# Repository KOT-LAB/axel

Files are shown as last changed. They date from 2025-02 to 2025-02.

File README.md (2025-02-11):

# Axel: Your framework for custom BLDC motor controller

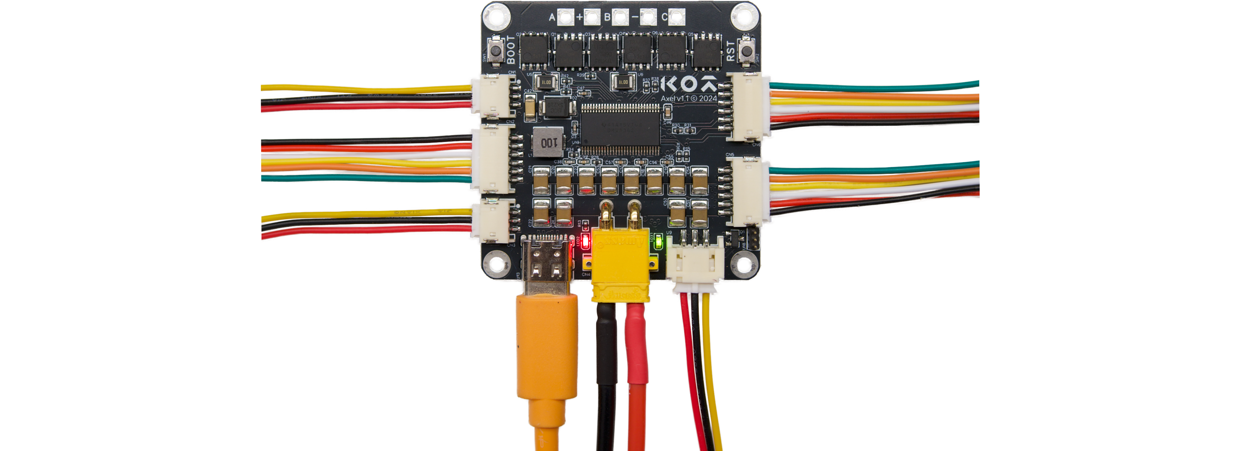
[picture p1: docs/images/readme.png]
Axel Board
  

---

## 🚀 What is Axel?

Axel is an **open-source BLDC motor controller** designed to empower makers, enthusiasts, and researchers. It's a versatile hardware framework for developing custom firmware tailored to your specific application. Think of it as your "**Arduino for BLDC motor control**," combining flexibility, user-friendliness, and powerful performance to support a wide range of projects for both beginners and professionals.

### **Key Advantages:**
- **Flexibility In Motor-Controller Setup:** Features a built-in encoder for direct mounting on the motor and also supports external encoders.
- **Built-in Current Sensing:** Enables true Field-Oriented Control (FOC) for precise and efficient motor control.
- **High-Performance:** Based on the STM32 and a powerful gate driver with external MOSFETs, meets demands of any application.
- **Extensive Connectivity:** Has all most popular interfaces on board, makes the integration with your application seamless.
- **Full compatibility with SimpleFOC:** Makes it easy to start for beginners and enables rapid development for professionals.
- **Flexible Development:** Write your own firmware from scratch to maximize performance, or customize our basic firmware and leverage full SimpleFOC compatibility for rapidness.
- **Beginner-Friendliness:** SimpleFOC support, clear documentation, basic firmware that works out of the box, and an extensive set of examples make getting started easy.

### Applications

- **Legged Robots:** High-speed and high-precision motion control for dynamic robotics.
- **Exoskeletons:** Reliable torque and speed control for assistive devices.
- **Electric Vehicles:** Scalable design for mobility solutions.
- **CNC Machines & 3D Printers:** Precise control in automated manufacturing.
- **Anything else:** The only limit is your imagination!

### **Is Axel for you?**

- **Enthusiasts**: Power *any project* with a *versatile* and *high-performance* BLDC motor controller that’s easy to integrate and customize.
- **Researchers**: Explore cutting-edge motor control concepts with a platform designed for *experimentation and innovation*. Axel provides a *powerful framework* for developing, testing, and iterating on new ideas.
- **Startups**: Jump straight into developing a *tailor-made solution* for your application. No need to set up manufacturing. Its *rich base of examples* and *SimpleFOC support* make firmware development easy and efficient.
- **Enterprises**: Minimize *external dependencies* by building your *custom in-house solution* on Axel. Perfect for *fast internal development* and *prototyping* before committing to large-scale designs.

---

## 📈 Project Status

**In January 2025, we decided to turn Axel from a solely hardware project into a software one as well.** Now, we've started actively working on `/tests`, `/examples`, and `/firmware`. Expect first commits in February!

### **Current Development Stage:**

- **Production Status:** Axel’s production is **currently frozen** due to a recently discovered major hardware bug. We are diligently working to resolve this issue.
- **Example Code Development:** Expanding the `/examples` directory with practical applications and demonstrations.
- **Firmware Development:** Actively working on a basic firmware that serves as a solid foundation for your custom firmware development in `/firmware`.
- **Hardware Tests:** Focused on enriching hardware validation tests to ensure reliable performance in `/tests`.

---

## 📊 Main Parameters

| **Parameter** | **Value** |
|---|---|
| **Input Voltage** | 10-54V |
| **Peak Phase Current** | 100A |
| **Peak Electrical Power** | 3100W |
| **Continuous Electrical Power** | 1100W |
| **MCU** | STM F446RE |
| **Driver** | TI DRV8302 |
| **Encoder** | AS5047P |
| **Interfaces** | SPI, I2C, CAN FD, UART, USB-C |
| **Programming interfaces** | SWD, DFU |
| **Dimensions** | 50x50x9mm |

---

## 🛠️ Dive deeper & How it works

For more in-depth information about Axel, refer to the following documents:

- **[Hardware Details](docs/hardware.md)** – Explore hardware features, the PCB design, schematics, and component choices behind Axel.
- **[SimpleFOC Support](docs/simplefoc_support.md)** – Understand how Axel integrates with SimpleFOC for simplified motor control development.
- **[Getting Started](docs/getting_started.md)** – Begin using Axel with setup instructions, toolchain details, and firmware installation.
- **[Documentation](docs/README.md)** - Learn more about Axel.

These documents provide essential details for both beginners and advanced users who want to make the most of Axel.

---

## 🗂️ Directory Structure

```
Axel/
├── hardware/               # Schematics, PCB layouts, photos, hardware docs, 3D models
│   ├── schematics/         # Circuit diagrams and electrical schematics
│   ├── mechanical/         # 3D models, enclosures, and mounting designs
│   └── media/              # Renders and photos of Axel
├── firmware/               # (coming soon) Base firmware for custom development
├── examples/               # (coming soon) Example code for different control modes
├── tests/                  # (coming soon) Hardware tests
├── utils/                  # Utils for development
├── docs/                   # Additional documentation & images
├── LICENSE                 # MIT License for firmware
├── LICENSE-HARDWARE.md     # CERN-OHL-P License for hardware
└── README.md               # This file
```

---

## 🙏 Credits and Special Thanks

This project wasn't possible without the active members of Axel's team. Special thanks to:

- ***Arsenii Mironov*** - idea, project management, software and setting up manufacturing
- ***Peter Germanovich*** - product management
- ***Andrei Belov*** - electrical engineering
- ***Alina Petrovskaya*** - marketing materials
- ***Richard Unger*** - advising on hardware design
- ***Rostislav Likhogrud*** - general supervision

Axel’s development was inspired by the incredible work of the open-source community. Special thanks to:

- **[MIT Mini Cheetah Controller](https://github.com/bgkatz)** by ***Ben Katz*** – A key reference during Axel’s hardware design.

---

## 🤝 Contribution and Support

We welcome contributions to Axel! Whether it’s code, hardware feedback, or documentation improvements, please check out our **[CONTRIBUTING.md](CONTRIBUTING.md)** to get started.

If you’ve found an issue or have a feature request, feel free to **[open an issue](https://github.com/KOT-LAB/axel/issues)**.

Another great way to support the team and future development is to buy our hardware at **[Emotor.Market](https://emotor.market/)**. Axel will be available again there at the best price once the final bugs are resolved.

---

## 📜 License

Axel is licensed under a dual-license model:

- **Firmware:** Licensed under the **[MIT License](LICENSE)**. This allows for free use, modification, and distribution of the firmware, even for commercial purposes, with proper attribution.
- **Hardware:** Licensed under the **[CERN Open Hardware License (CERN-OHL-P)](LICENSE-HARDWARE.md)**. This ensures that any modifications or derivatives of the hardware design remain open-source.

---

## 📬 Contact

For questions, feedback, or commercial inquiries, reach us at **[made@kot.works](mailto:made@kot.works)**.

---

*Built with passion for makers, innovators, and dreamers. Let Axel power your next big idea!*

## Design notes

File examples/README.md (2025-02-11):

# Axel Examples  

This directory contains example projects demonstrating various control modes and functionalities of the Axel controller. Each example is organized as a standalone **[PlatformIO](https://platformio.org/)** project on the **[Arduino framework](https://docs.platformio.org/en/latest/frameworks/arduino.html)**, making it easy to compile and upload to the board.  

---

## Structure  

Each example follows the standard **[PlatformIO](https://platformio.org/)** project structure:  

```
example/
├── src/                   # Source code files
├── include/               # Header files
├── lib/                   # External libraries (e.g., SimpleFOC)
├── platformio.ini         # Project configuration file
└── README.md              # Description of the example
```

---

## Available Examples  

- `blink`  
- `basic_position_control`  
- `basic_velocity_control`  
- `basic_torque_control`  
- `advanced_position_control`  

Each example has its own `README.md` with details on functionality, usage, and expected behavior.  

---

## Getting Started  

1. Open an example directory in PlatformIO.  
2. Refer to the example-specific README for configuration and usage details.  
3. Build and upload the project to your Axel board.  

---

For more information on using PlatformIO with Axel, refer to the main [firmware/](../firmware/) README.

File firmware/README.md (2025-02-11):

# Axel Basic Firmware

Welcome to the **Axel Firmware** directory! This firmware serves as a **foundation** for developing custom BLDC motor control applications using the Axel controller.

---
## ⚠️ Announcement

**In January 2025, we decided to turn Axel from a solely hardware project into a software one as well.** Now, we've started actively working on `/tests`, `/examples`, and `/firmware`. Expect first commits in February!

Currently, we are resolving a **major hardware bug** that was recently discovered. Once this issue is resolved, we will implement the basic firmware according to its description in this file. Development is actively ongoing!

---

## 🚀 Overview

This **basic firmware** is organized as a **[PlatformIO](https://platformio.org/)** project, making it easy to build, upload, and manage dependencies across different development environments. 

For simplicity and ease of development, this firmware is based on **[SimpleFOC](https://github.com/simplefoc/Arduino-FOC)**, a widely-used open-source library for BLDC motor control. Learn more about Axel's compatibility with SimpleFOC [docs/simplefoc_support.md](../docs/simplefoc_support.md).

This **"basic" firmware** aims to:

- Provide **basic motor control functionality** out of the box.
- Ensure the **board operates correctly** with minimal configuration.
- Serve as a **starting point** for custom firmware development.

---

## ⚙️ Features

- **Motor Control:** implements control in position, velocity, and torque modes.
- **Sensor Integration:** uses on-board encoder.
- **Communication Interfaces:** uses CAN FD as a main control bus and can be configured via USB-C for your specific setup.
- **SimpleFOC Integration:** Easy-to-understand APIs for rapid development.

---

## 📂 Directory Structure

```
firmware/
├── src/                   # Source code files
├── include/               # Header files
├── lib/                   # External libraries (SimpleFOC, etc.)
├── platformio.ini         # Project configuration file (PlatformIO)
└── README.md              # This file
```

---

## ⚡ Getting Started

1. **Review our basic getting started guide at [docs/getting_started.md](../docs/getting_started.md)**.

2. **Clone the Repository:**
   ```bash
   git clone https://github.com/KOT-LAB/axel.git
   cd axel/firmware
   ```
3. **Build and Upload:**
   ```bash
   pio run --target upload
   ```

---

## 📚 Documentation

- **Axel Hardware Documentation:** Refer to the `/docs` directory in the main repository.
- **SimpleFOC Documentation:** [https://docs.simplefoc.com/](https://docs.simplefoc.com/)

---

## 🤝 Contributions

We welcome contributions to improve the firmware. Check out the main [CONTRIBUTING.md](../CONTRIBUTING.md) for guidelines.

---

*Happy hacking and motor controlling with Axel!*

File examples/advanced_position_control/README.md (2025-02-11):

# Advanced Position Control example

## Overview

This example demonstrates **position control** on the Axel controller using the SimpleFOC library **with inline current sensing**. It is based on the [official SimpleFOC examples](https://github.com/simplefoc/Arduino-FOC/blob/master/examples/motion_control/position_motion_control/magnetic_sensor/angle_control/angle_control.ino) and closely follows the recommended practices for inline current sensing outlined in the [SimpleFOC documentation](https://docs.simplefoc.com/inline_current_sense). The firmware configures the motor for **position-based control**, sets up the on-board encoder and driver, and **activates current sensing** to improve performance, reliability, and protection.

> **Note:** Unlike the [basic_position_control](../basic_position_control) example, this **advanced example** takes advantage of Axel’s **current sensing capability** for better FOC performance and real-time current monitoring.

---

## Objectives

- Show **SimpleFOC's seamless integration** with Axel.
- Set up the Axel's specific hardware: **on-board AS5047P encoder**, **DRV8302 driver** and **current sensing**.
- Demonstrate how to **integrate and utilize current sensing** in Axel’s FOC workflow.
- Show **improved current feedback**, resulting in **more efficient torque controle*.
- Illustrate the recommended initialization order and usage of `current_sense` in code in conjunction with the **on-board DRV8302 driver** and **AS5047P encoder**.

---

## Why Use Current Sensing?

The inclusion of current sensing significantly boosts the controller’s capabilities:

1. **Improved FOC accuracy**: By monitoring phase currents in real time, the controller can maintain **more precise field alignment** and deliver superior torque performance.
2. **Overcurrent protection**: Real-time current feedback helps you **detect and prevent dangerous overcurrent conditions** quickly, safeguarding your hardware.
3. **Enhanced tuning**: Being able to observe and fine-tune current loops offers **deeper insight** into motor behavior, allowing for tighter control and **improved efficiency**.

---

## Setup Instructions

This example uses the same fundamental setup as the **basic_position_control** example, but adds pins and configuration parameters for current sensing.

### 1. General Hardware Setup

Before using this example, ensure you have assembled your **motor and controller** correctly. Please refer to **[`hardware_setup.md`](./docs/hardware_setup.md)** for a step-by-step guide.

### 2. Connecting the Axel Controller

To run this example, follow these steps:

1. **Power the Board:**
   - Ensure that the Axel controller is connected to a **suitable power source**.
   - The **main power supply** should match the `#define SUPPLY_VOLTAGE` set in `main.cpp`.
2. **Connect USB-C:**
   - Connect **USB-C** to your computer to enable **serial logging, debugging and control interface**.
3. **Choose an Upload Method:**
   - You can upload the firmware using either **SWD (ST-Link)** or **DFU (Device Firmware Upgrade)**.
   - Edit `platformio.ini` to select the appropriate upload method:

   #### **Using ST-Link (default method)**

   ```ini
   upload_protocol = stlink
   ```

   #### **Using DFU (alternative method)**

   ```ini
   ; upload_protocol = stlink  ; Comment this out
   upload_protocol = dfu       ; Uncomment this to use DFU mode
   ```

### 3. Configure #define Values in main.cpp

Edit the following parameters to fit your **specific hardware** and tuning needs:

- **Motor pole pairs:** `#define MOTOR_POLE_PAIRS`
- **Power supply voltage:** `#define SUPPLY_VOLTAGE`
- **Control parameters (e.g., PID gains, velocity limits, etc.)`

---

## Building and Running the Example

### 1. Build the Project

Open a terminal in the project directory and run:

```bash
pio run
```

### 2. Upload the Firmware

```bash
pio run --target upload
```

### 3. Monitor the Serial Output

Once uploaded, monitor the serial output:

```bash
pio device monitor -b 115200
```

---

## Expected Behavior

When you run this example, you should observe:

- **Initialize the serial monitor and debugging.**
- **Set up and calibrate the magnetic sensor.**
- **Configure the driver (including any DRV8302-specific settings).**
- **Motor and current sense initialization**
- **Initialize the BLDC motor with the appropriate FOC settings and PID parameters.**
- **Real-time current feedback used within the FOC loop for precise torque control**.
- **Continuously run the FOC algorithm and adjust the motor’s position based on the serial input target.**

---

If anything doesn’t work as expected, check your wiring, power supply, and motor parameters. For further assistance, feel free to reach out! 🚀

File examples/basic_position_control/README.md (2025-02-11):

# Basic Position Control example

## Overview

This example demonstrates **position control** on the Axel controller using the SimpleFOC library. It is based on the [official SimpleFOC example](https://github.com/simplefoc/Arduino-FOC/blob/master/examples/motion_control/position_motion_control/magnetic_sensor/angle_control/angle_control.ino) but has been adapted to work with Axel. The example configures the motor for **position-based control**, setups on-board encoder and driver, and allows position commands via USB-C serial communication.

> **Note:** This is the most basic position control example. It does **not** take advantage of Axel's advanced features like current sensing for FOC. If you need to see how current sensing can be integrated into position control, please refer to the **`[advanced_positin_control](./examples/advanced_position_control)`** directory.

---

## Objectives

- Show **SimpleFOC's seamless integration** with Axel.
- Set up the Axel's specific hardware: **on-board AS5047P encoder** and **DRV8302 driver**.
- Implement **basic positin control** as a foundation for custom firmware enhancements.

---

## Setup Instructions

---

### 1. General Hardware Setup

Before using this example, ensure you have assembled your **motor and controller** correctly. Please refer to **[`hardware_setup.md`](./docs/hardware_setup.md)** for a step-by-step guide.

### 2. Connecting the Axel Controller

To run this example, follow these steps:

1. **Power the Board:**
   - Ensure that the Axel controller is connected to a **suitable power source**.
   - The **main power supply** should match the `#define SUPPLY_VOLTAGE` set in `main.cpp`.
2. **Connect USB-C:**
   - Connect **USB-C** to your computer to enable **serial logging, debugging and control interface**.
3. **Choose an Upload Method:**
   - You can upload the firmware using either **SWD (ST-Link)** or **DFU (Device Firmware Upgrade)**.
   - Edit `platformio.ini` to select the appropriate upload method:

#### **Using ST-Link (default method)**

    ```ini
    upload_protocol = stlink
    ```

#### **Using DFU (alternative method)**

    ```ini
    ; upload_protocol = stlink  ; Comment this out
    upload_protocol = dfu       ; Uncomment this to use DFU mode
    ```

### 3. Configure `#define` Values in `main.cpp`

Before building, make sure to configure the following **user-specific parameters** in `main.cpp` in accordance to your particular setup:

- **Motor pole pairs:** `#define MOTOR_POLE_PAIRS`
- **Power supply voltage:** `#define SUPPLY_VOLTAGE`
- **Control parameters (e.g., PID gains, velocity limits, etc.)`

---

## Building and Running the Example

### 1. Build the Project

From the terminal in the project directory, run:

```sh
pio run
```

### 2. Upload the Firmware

```sh
pio run --target upload
```

### 3. Monitor Serial Output

Once uploaded, monitor the serial output:

```sh
pio device monitor -b 115200
```

---

## Expected Behavior

When you run this example, you can expect it to:

- **Initialize the serial monitor and debugging.**
- **Set up and calibrate the magnetic sensor.**
- **Configure the driver (including any DRV8302-specific settings).**
- **Initialize the BLDC motor with the appropriate FOC settings and PID parameters.**
- **Continuously run the FOC algorithm and adjust the motor’s position based on the serial input target.**

---

If anything doesn’t work as expected, check your wiring, power supply, and motor parameters. For further assistance, feel free to reach out! 🚀

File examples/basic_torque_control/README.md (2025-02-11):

# Basic Torque Control example

## Overview

This example demonstrates **torque control** on the Axel controller using the SimpleFOC library. It is based on the [official SimpleFOC example](https://github.com/simplefoc/Arduino-FOC/blob/master/examples/motion_control/torque_control/magnetic_sensor/voltage_control/voltage_control.ino) but has been adapted to work with Axel. In this example, motor torque is controlled by **setting the voltage** rather than directly reading or regulating current. 

> **Note:** This is the most basic torque control example. It does **not** take advantage of Axel’s advanced features like hardware current sensing. For more advanced control approaches (including true current-based torque control), please refer to other examples or future advanced example directories.

---

## Objectives

- Show **SimpleFOC's seamless integration** with Axel in torque control mode.
- Configure Axel’s specific hardware: **on-board AS5047P encoder** and **DRV8302 driver**.
- Implement **basic voltage-based torque control** as a foundation for more sophisticated FOC solutions.

---

## Setup Instructions

---

### 1. General Hardware Setup

Before using this example, ensure you have assembled your **motor and controller** correctly. Please refer to **[hardware_setup.md](./docs/hardware_setup.md)** for a step-by-step guide.

### 2. Connecting the Axel Controller

To run this example, follow these steps:

1. **Power the Board:**
   - Ensure that the Axel controller is connected to a **suitable power source**.
   - The **main power supply** should match the `#define SUPPLY_VOLTAGE` set in `main.cpp`.
2. **Connect USB-C:**
   - Connect **USB-C** to your computer to enable **serial logging, debugging, and control interface**.
3. **Choose an Upload Method:**
   - You can upload the firmware using either **SWD (ST-Link)** or **DFU (Device Firmware Upgrade)**.
   - Edit `platformio.ini` to select the appropriate upload method:

#### **Using ST-Link (default method)**

```ini
upload_protocol = stlink
```

#### **Using DFU (alternative method)**

```ini
; upload_protocol = stlink  ; Comment this out
upload_protocol = dfu       ; Uncomment this to use DFU mode
```

### 3. Configure `#define` Values in `main.cpp`

Before building, make sure to configure the following **user-specific parameters** in `main.cpp` in accordance with your particular setup:

- **Motor pole pairs:** `#define MOTOR_POLE_PAIRS`
- **Power supply voltage:** `#define SUPPLY_VOLTAGE`
- **Control parameters (e.g., alignment voltage, etc.)**

---

## Building and Running the Example

### 1. Build the Project

From the terminal in the project directory, run:

```sh
pio run
```

### 2. Upload the Firmware

```sh
pio run --target upload
```

### 3. Monitor Serial Output

Once uploaded, monitor the serial output:

```sh
pio device monitor -b 115200
```

---

## Expected Behavior

When you run this example, you can expect it to:

- **Initialize the serial monitor and debugging.**
- **Set up and calibrate the magnetic sensor.**
- **Configure the driver (including any DRV8302-specific settings).**
- **Initialize the BLDC motor with the appropriate FOC settings and PID parameters.**
- **Continuously run the FOC algorithm and adjust the motor’s torque (voltage) based on the serial input target.**

---

If anything doesn’t work as expected, check your wiring, power supply, and motor parameters. For further assistance, feel free to reach out! 🚀

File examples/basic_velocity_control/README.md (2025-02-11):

# Basic Velocity Control example

## Overview

This example demonstrates **velocity control** on the Axel controller using the SimpleFOC library. It is based on the [official SimpleFOC example](https://github.com/simplefoc/Arduino-FOC/blob/master/examples/motion_control/velocity_motion_control/magnetic_sensor/velocity_control/velocity_control.ino) but has been adapted to work with Axel. The example configures the motor for **velocity-based control**, sets up the on-board encoder and driver, and allows velocity commands via USB-C serial communication.

> **Note:** This is the most basic velocity control example. It does **not** take advantage of Axel's advanced features like current sensing for FOC. If you need to see how current sensing can be integrated into your motor control, please refer to the **`[advanced_velocity_control](./examples/advanced_velocity_control)`** directory or other advanced examples.

---

## Objectives

- Demonstrate **SimpleFOC's seamless integration** with Axel for velocity control.
- Configure Axel’s specific hardware: **on-board AS5047P encoder** and **DRV8302 driver**.
- Implement **basic velocity control** as a foundation for custom firmware enhancements.

---

## Setup Instructions

---

### 1. General Hardware Setup

Before using this example, ensure you have assembled your **motor and controller** correctly. Please refer to **[`hardware_setup.md`](./docs/hardware_setup.md)** for a step-by-step guide.

### 2. Connecting the Axel Controller

To run this example, follow these steps:

1. **Power the Board:**
   - Ensure that the Axel controller is connected to a **suitable power source**.
   - The **main power supply** should match the `#define SUPPLY_VOLTAGE` set in `main.cpp`.
2. **Connect USB-C:**
   - Connect **USB-C** to your computer to enable **serial logging, debugging, and control interface**.
3. **Choose an Upload Method:**
   - You can upload the firmware using either **SWD (ST-Link)** or **DFU (Device Firmware Upgrade)**.
   - Edit `platformio.ini` to select the appropriate upload method:

#### **Using ST-Link (default method)**

```ini
upload_protocol = stlink
```

#### **Using DFU (alternative method)**

```ini
; upload_protocol = stlink  ; Comment this out
upload_protocol = dfu       ; Uncomment this to use DFU mode
```

### 3. Configure `#define` Values in `main.cpp`

Before building, make sure to configure the following **user-specific parameters** in `main.cpp` according to your setup:

- **Motor pole pairs:** `#define MOTOR_POLE_PAIRS`
- **Power supply voltage:** `#define SUPPLY_VOLTAGE`
- **Control parameters (PID gains, velocity ramp, etc.)**

---

## Building and Running the Example

### 1. Build the Project

From the terminal in the project directory, run:

```sh
pio run
```

### 2. Upload the Firmware

```sh
pio run --target upload
```

### 3. Monitor Serial Output

Once uploaded, monitor the serial output:

```sh
pio device monitor -b 115200
```

---

## Expected Behavior

When you run this example, you can expect it to:

- **Initialize the serial monitor and debugging.**
- **Set up and calibrate the magnetic sensor.**
- **Configure the driver (including any DRV8302-specific settings).**
- **Initialize the BLDC motor with the appropriate FOC settings and PID parameters.**
- **Continuously run the FOC algorithm and adjust the motor’s velocity based on the serial input target.**

---

If anything doesn’t work as expected, check your wiring, power supply, and motor parameters. For further assistance, feel free to reach out! 🚀
```

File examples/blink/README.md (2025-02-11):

# Blink Example for Axel

## Overview

This example demonstrates a simple **LED blink** program on the Axel controller using the **Arduino framework**. It verifies that the board is correctly powered and running firmware by toggling the onboard LED.

---

## Objectives

- Verify that the **Axel board** is powered and functioning correctly.
- Demonstrate **basic GPIO control** using the onboard LED.
- Provide a minimal **PlatformIO project setup** for Axel.

---

## Setup Instructions

### 1. General Hardware Setup

Before using this example, ensure your **Axel board is connected properly**. Please refer to **`./docs/hardware_setup.md`** for general setup instructions.

---

### 2. Connecting the Axel Controller

To run this example, follow these steps:

1. **Power the Board:**
   - Ensure that the Axel controller is connected to a **suitable power source**.
2. **Connect USB-C:**
   - Connect **USB-C** to your computer to enable **serial logging and debugging** (if needed).
3. **Choose an Upload Method:**
   - You can upload the firmware using either **SWD (ST-Link)** or **DFU (Device Firmware Upgrade)**.
   - Edit `platformio.ini` to select the appropriate upload method:

#### **Using ST-Link (default method)**
```ini
upload_protocol = stlink
```

#### **Using DFU (alternative method)**
```ini
; upload_protocol = stlink  ; Comment this out
upload_protocol = dfu       ; Uncomment this to use DFU mode
```

---

### 3. Configure `#define` Values in `main.cpp`

Before building, you can modify the **blink interval** by adjusting the delay values inside `main.cpp`:

```cpp
#define BLINK_DELAY 500 // Change to modify blink rate
```

---

## Building and Running the Example

### 1. Build the Project

In the terminal, navigate to the project directory and run:

```sh
pio run
```

### 2. Upload the Firmware

```sh
pio run --target upload
```

### 3. Monitor Serial Output (Optional)

Although this example does not include serial logging, you can open a serial monitor to confirm board activity:

```sh
pio device monitor -b 115200
```

---

## Expected Output

- The **onboard LED** (connected to `PA2`) should continuously **blink** at a 1-second interval (500ms ON, 500ms OFF).
- If the LED is not blinking, check:
  - Power supply.
  - Upload method (SWD or DFU).
  - Correct PlatformIO configuration.

---

This example provides a simple way to test GPIO functionality on Axel. If the LED is blinking, your board is working correctly! 🚀

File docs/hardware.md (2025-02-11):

# Axel Hardware Overview

Axel is designed as a versatile, high-performance open-source BLDC motor controller. This document details the core hardware components and interfaces that make Axel a powerful and flexible solution for motor control applications.

---

## ⚙️ Key Components

Axel integrates carefully selected components to achieve high efficiency, precision, and versatility:

- **Microcontroller:** STM32F446RE  
  - 180MHz Cortex-M4F MCU with DSP and floating-point unit.
  - Rich set of peripherals suitable for motor control applications.
  - High computational performance optimal for even most demanding applications.

- **Motor Driver:** TI DRV8302  
  - Three-phase gate driver for BLDC motors for high-power applications
  - Supports a wide operating voltage range of **8V to 60V**.
  - Integrated overcurrent protection.

- **Encoder:** AS5047P  
  - High-resolution **14-bit rotary position sensor**.
  - Capable of high-speed angular measurement over **360 degrees**.
  - Dynamic angle error compensation for precise feedback in high-speed motor control.

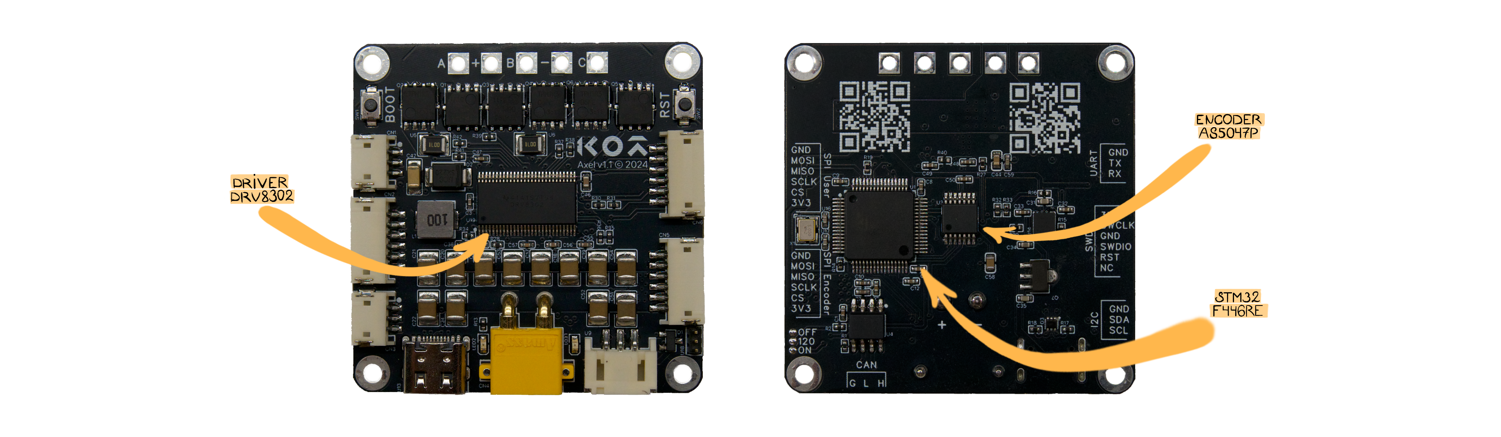
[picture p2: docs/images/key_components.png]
Key Components


---

## 🔌 Interfaces

Axel is equipped with multiple communication and control interfaces to ensure maximum compatibility with various applications:

### **Communication Interfaces**
- **x2 SPI (Serial Peripheral Interface)**  
  - High-speed communication with external encoders and sensors.
  - Can be used as a control bus in specific applications.

- **x1 I2C (Inter-Integrated Circuit)**  
  - Suitable for low-speed sensor interfacing (e.g., thermistors, IMUs, environmental monitors).

- **x1 CAN FD (Controller Area Network - Flexible Data Rate)**  
  - Robust, high-speed communication standard for distributed control systems.
  - Ideal for applications in robotics, automotive, and industrial automation.

- **x1 UART (Universal Asynchronous Receiver-Transmitter)**  
  - Commonly used for debugging, calibration, and interfacing with external modules.

- **x1 USB Type-C**  
  - High-speed data exchange.
  - Supports debugging, DFU (Device Firmware Upgrade) flashing, and serial communication.

### **Programming Interfaces**
- **SWD (Serial Wire Debug)**  
  - Standard ARM debugging interface.
  - Used for firmware development and real-time debugging.

- **DFU (Device Firmware Upgrade)**  
  - Enables firmware flashing over USB without external programmers.

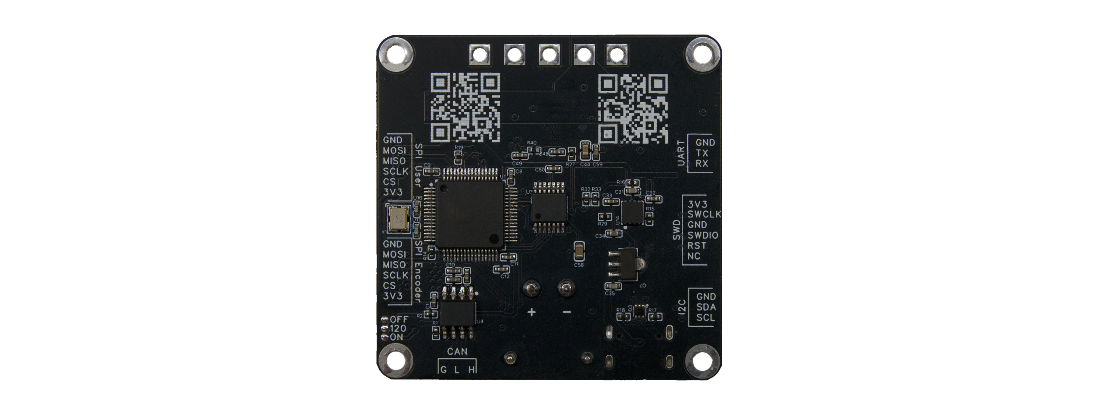
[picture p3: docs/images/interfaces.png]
Interfaces


---

## 🏗️ Future Enhancements
We continuously improve Axel’s hardware and software ecosystem. If you have suggestions or need additional technical details, feel free to contribute or reach out to the team.

For more information on contributing and getting involved, please refer to **[CONTRIBUTING.md](../CONTRIBUTING.md)**.

---

**Axel – Your open-source platform for powerful and flexible BLDC motor control!**

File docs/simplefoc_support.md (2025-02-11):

# SimpleFOC Support for Axel

## 🔗 **Compatibility with SimpleFOC**

Axel is fully compatible with **[SimpleFOC](https://github.com/simplefoc/Arduino-FOC)**, a popular open-source library for BLDC motor control. This compatibility allows you to:

- **Simplify Development:** Leverage SimpleFOC’s high-level APIs to control motors without deep expertise in BLDC control algorithms.
- **Quick Start:** Run example projects with minimal setup using pre-configured SimpleFOC code.
- **Flexible Customization:** Modify and extend firmware easily, thanks to SimpleFOC’s modular design.

This integration makes Axel the perfect choice for both beginners and advanced developers working on BLDC projects.

---

## ⚙️ Why it works?

All the main components of Axel are fully supported by SimpleFOC:

- **Motor Driver: TI DRV8302**

  - Supported by SimpleFOC for three-phase motor control.
  - More here: **[DRV8302 SimpleFOC Example](https://docs.simplefoc.com/drv8302_example)**.

- **Encoder: AS5047P**

  - A high-resolution magnetic encoder with full compatibility.
  - More here: **[SimpleFOC AS5047 Driver](https://github.com/simplefoc/Arduino-FOC-drivers/tree/master/src/encoders/as5047)**.

- **Microcontroller: STM32F446RE**

  - Supported by SimpleFOC using the STM32 Arduino framework.
  - More here: **[SimpleFOC MCU Support](https://docs.simplefoc.com/stm32\_mcu)**

---

## 🚀 **Getting Started with SimpleFOC**

#### To begin using SimpleFOC with Axel, follow these steps:

##### 1. Installation in Arduino IDE

1. Open **Arduino IDE** and navigate to **Sketch > Include Library > Manage Libraries**.
2. Search for **SimpleFOC** in the Library Manager.
3. Click **Install** on the latest version.

For more details, refer to the **[SimpleFOC Library Download Guide](https://docs.simplefoc.com/library_download)**.

##### 2. Installation in PlatformIO**

1. Open **PlatformIO** in VS Code.
2. In **platformio.ini**, add the following line:
   ```ini
   lib_deps = SimpleFOC
   ```
3. Save the file and run a build to install the library.

For more details, refer to the **[SimpleFOC PlatformIO Guide](https://docs.simplefoc.com/library_platformio)**.

---

## 📖 **Understanding SimpleFOC**

We also encourage you to study **[SimpleFOC's documentation](https://docs.simplefoc.com/)**, particularly the **[Theory Corner](https://docs.simplefoc.com/theory_corner)**, to gain deeper insights into motor control principles.

---

## 🛠 **Working with Axel**

Now that SimpleFOC is installed, explore the `examples/` directory to see practical implementations of BLDC motor control with Axel.

---

## 🔗 **Additional Resources**

- **[SimpleFOC Documentation](https://docs.simplefoc.com/)**
- **[SimpleFOC GitHub Repository](https://github.com/simplefoc/Arduino-FOC)**

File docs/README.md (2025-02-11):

# Documentation

This directory contains essential documentation for understanding and working with Axel. Below is an overview of the available files:

- **getting_started.md** – A guide to setting up and using Axel for the first time.
- **hardware.md** – Detailed information on Axel’s hardware design, including specifications and key components.
- **hardware_setup.md** – Instructions for assembling, connecting, and configuring the hardware.
- **simplefoc_support.md** – Information on Axel’s compatibility with SimpleFOC and integration guidelines.
- **images/** – A collection of images, diagrams, and rendors used in the documentation.

For more details, refer to the individual files.

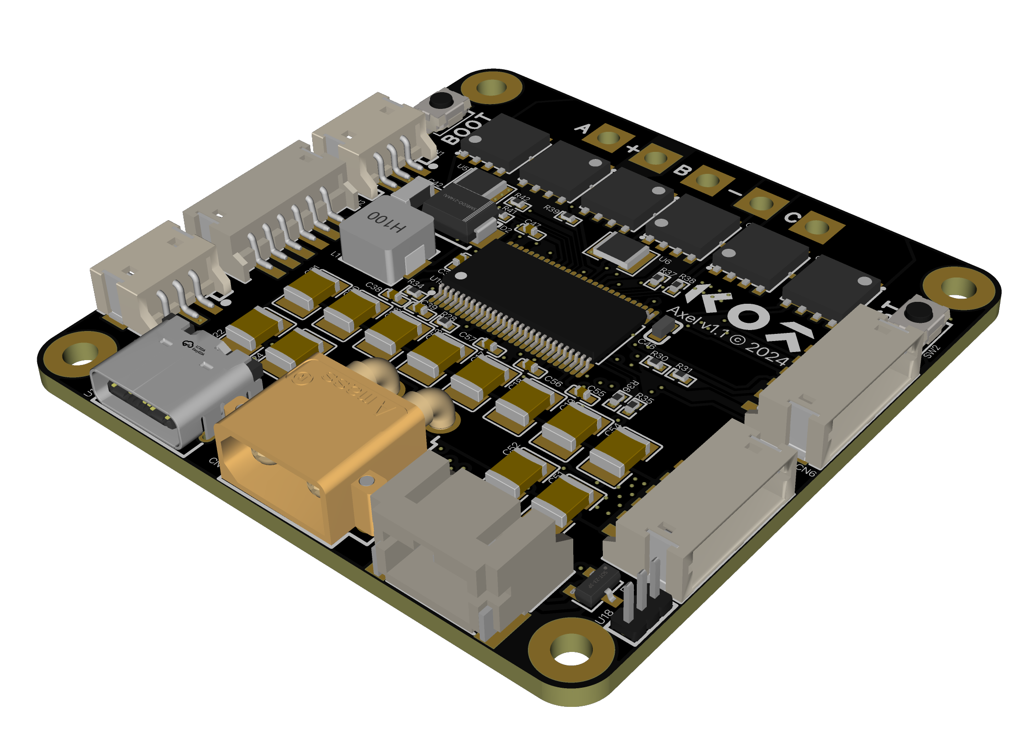
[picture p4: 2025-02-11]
hardware/media/render_view_2.png

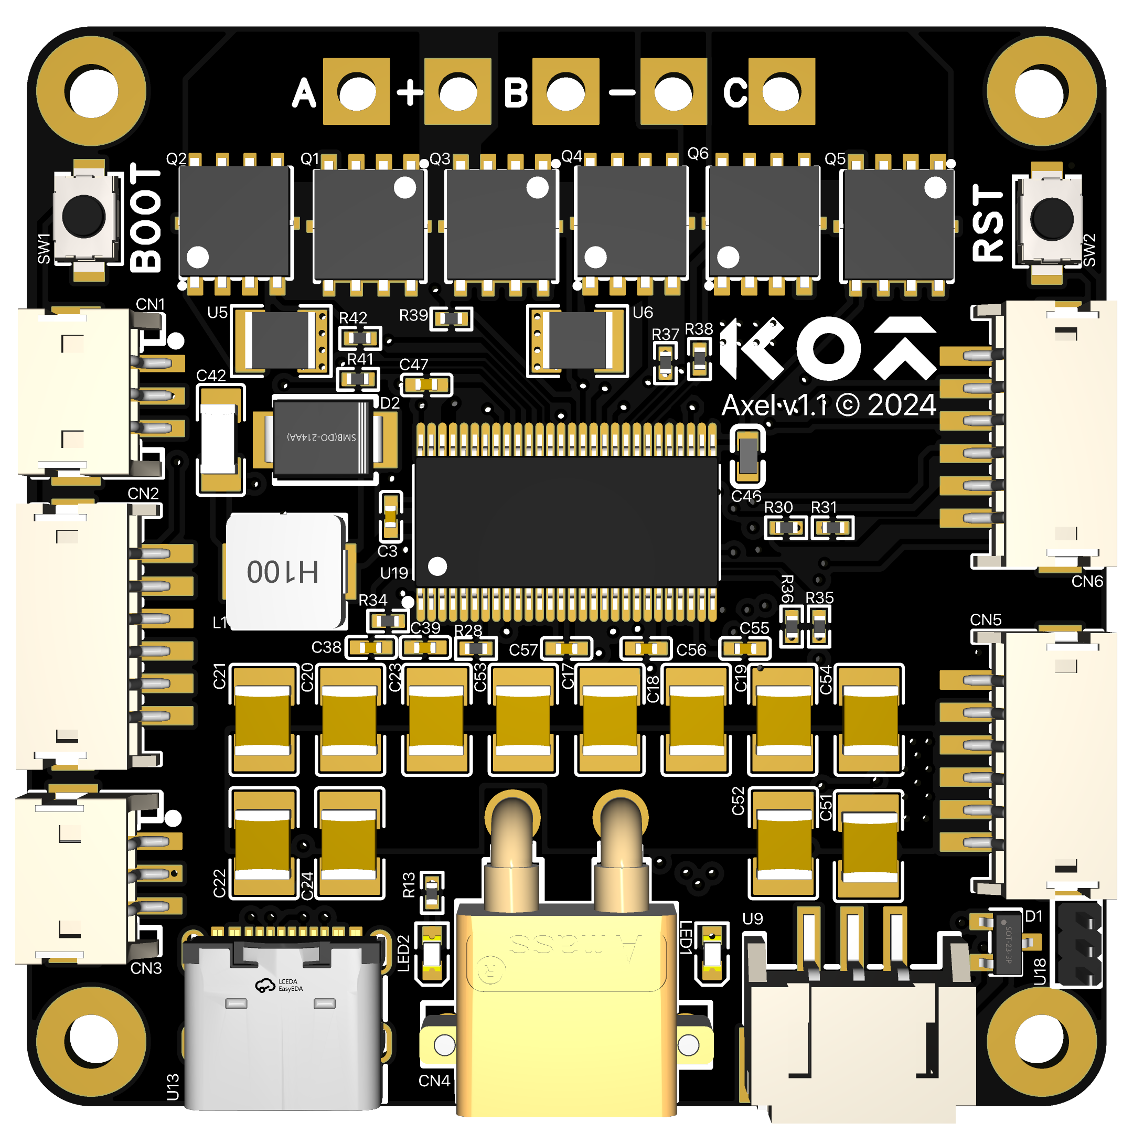
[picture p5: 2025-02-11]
hardware/media/render_view_4.png

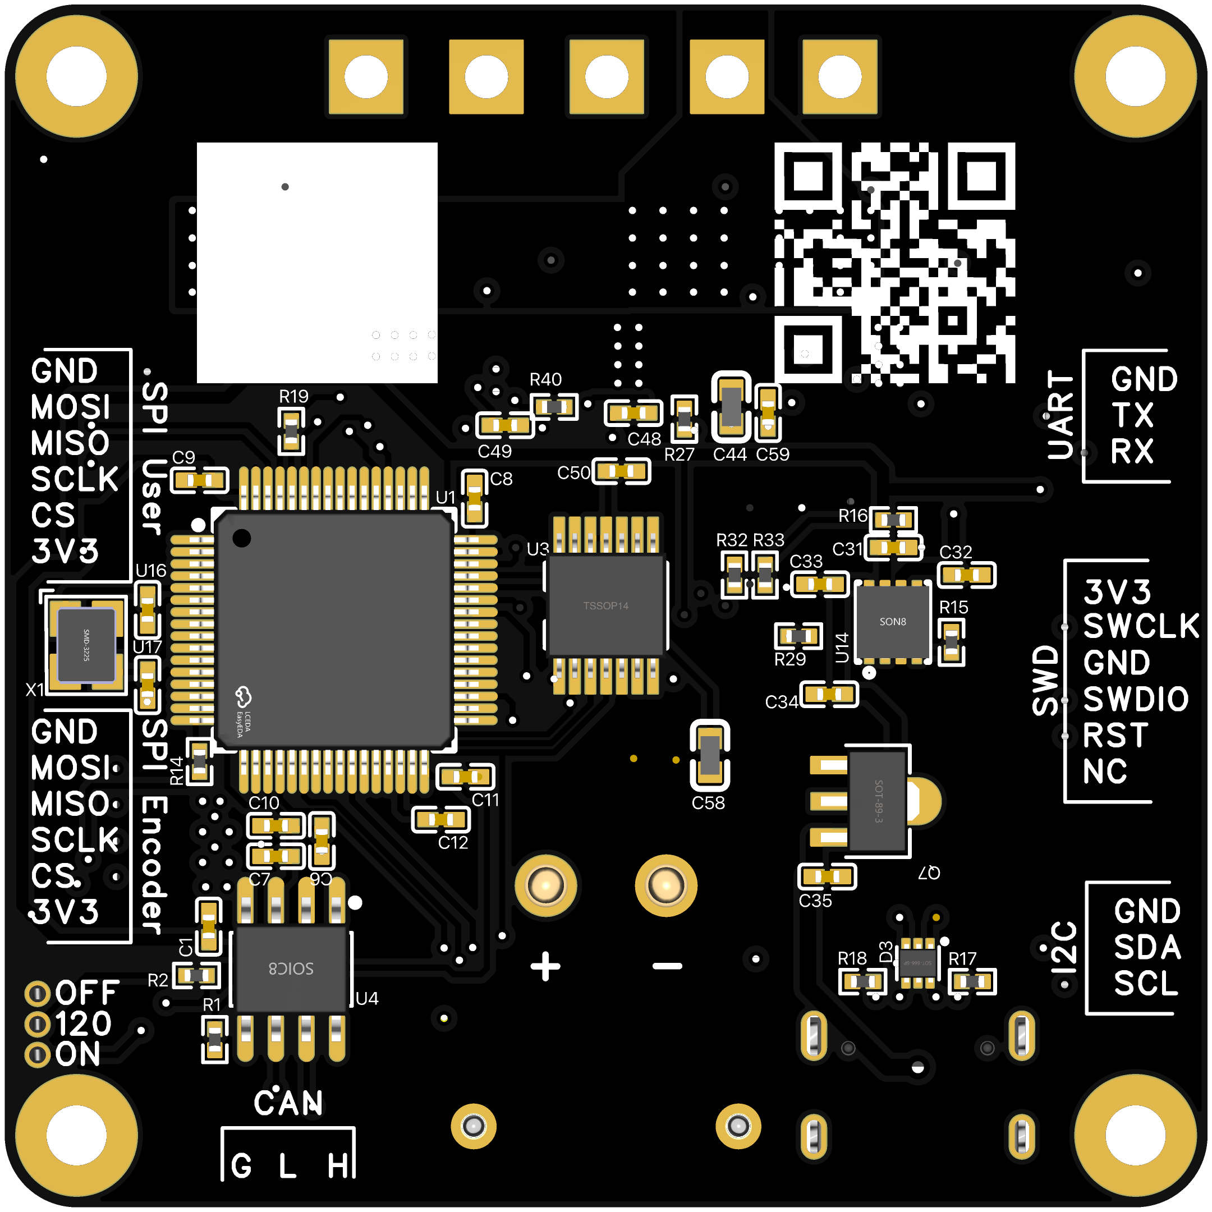
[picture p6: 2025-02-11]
hardware/media/render_view_5.png

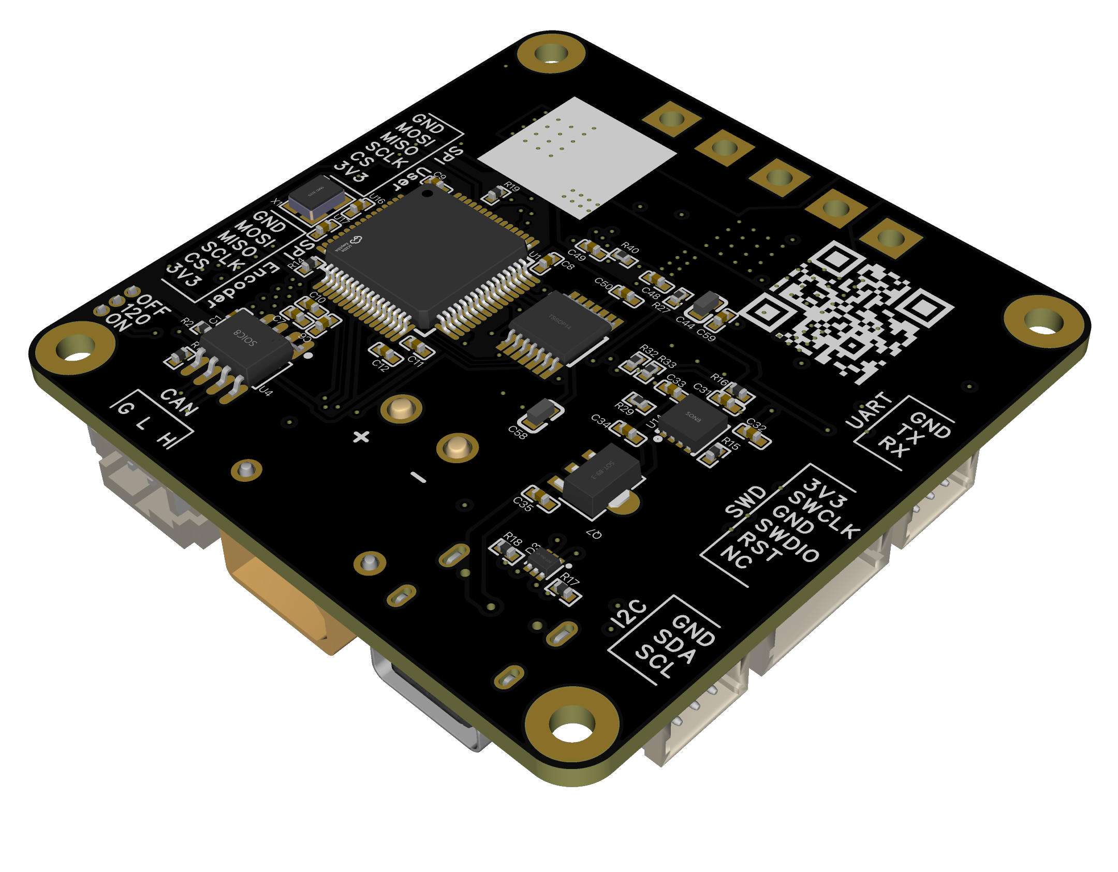
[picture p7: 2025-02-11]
hardware/media/render_view_3.png

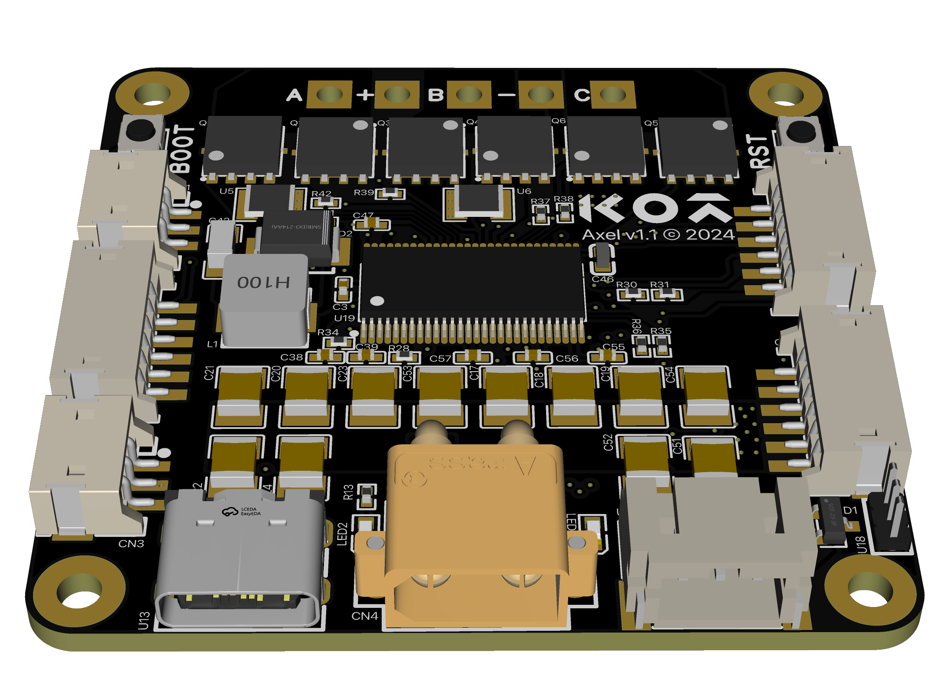
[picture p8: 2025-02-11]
hardware/media/render_view_1.png

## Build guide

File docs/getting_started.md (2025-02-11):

## 🚀 Getting Started with Axel

Axel is designed for seamless development using [PlatformIO](https://platformio.org/), a powerful ecosystem for embedded development. All software-related aspects of Axel—including the base firmware, examples, and hardware tests—are structured as **PlatformIO projects** for ease of use.

Follow these steps to set up your development environment and get started with Axel.

---

### 1️⃣ **Get Axel**

Get your Axel on **[Emotor.Market](https://emotor.market/)**.

---

### 2️⃣ **Prepare Your Hardware**

Before flashing firmware or running any tests, ensure your hardware is correctly assembled:

1. **Solder the Motor Phase Wires**

   - Axel has **three motor output phases** labeled **A, B, and C**.
   - Solder these to the appropriate motor wires—typically, BLDC motors have three wires corresponding to these phases.
   - If the motor spins in the wrong direction later, simply swap **any two** of the three phase connections.

2. **Check Power Connections**

   - Ensure your power supply matches **Axel’s voltage range (10-54V)**.
   - Double-check polarity before connecting.

---

### 3️⃣ **Set Up Your Development Environment**

1. **Install PlatformIO**\
   👉 Follow the installation steps in **[docs/simplefoc_support.md](simplefoc_support.md)**.

2. **Clone the Axel Repository**

   ```bash
   git clone https://github.com/KOT-LAB/axel.git
   cd axel
   ```

---

### 4️⃣ **Understanding the Project Structure**

**Axel organizes all software as **PlatformIO projects**, including:**

- `firmware/` – The base firmware for Axel.
- `examples/` – Example projects demonstrating different control modes.
- `tests/` – Hardware tests for debugging.

**A key file used across all projects is:**

- `pinout.h` (found in `firmware/`) – Defines Axel's hardware pin mappings. Always include this in your projects.

---

### 5️⃣ **Run Your First Test: Blinking an LED**

The simplest way to check if your board is functioning is to run the **Blink** example.

1. **Navigate to the example directory:**

   ```bash
   cd examples/blink
   ```

2. **Build and upload the code to your board:**

   ```bash
   pio run --target upload
   ```

4. **Check the LED** – If the LED blinks, your board is ready!

---

### 6️⃣ **Exploring SimpleFOC Examples**

Axel is fully compatible with **[SimpleFOC](https://github.com/simplefoc/Arduino-FOC)**, a popular BLDC motor control library. Before developing your own firmware, review these examples:

1. **Go to the [SimpleFOC repositry](https://github.com/simplefoc/Arduino-FOC).**

2. **Study the example codes**:

   - Open-loop control
   - Torque, velocity, and position control modes
   - Sensor-based feedback examples

---

### 7️⃣ **Run Your First BLDC Control Example**

To start with BLDC motor control, use the **Basic Torque Control** example.

1. **Navigate to the directory:**

   ```bash
   cd examples/basic_torque_control
   ```

2. **Carefully review the `README.md` to understand and set up the example.**

3. **Compile and upload the code:**

   ```bash
   pio run --target upload
   ```

---

### 8️⃣ **Next Steps**

Once comfortable with the basics, explore:
👉 **Firmware Customization** – Modify the `firmware/` and see what happens.
👉 **Advanced Control Modes** – Implement closed-loop control using encoders.
👉 **CAN, SPI, and UART Communication** – Develop multi-board applications.

For further details, visit the respective README files in `firmware/`, `examples/`, and `tests/`.

> **Note:** `firmware/` and `examples/` are still in development. Check out the **[Project Status](#📊-project-status)** section for the latest updates.

---

### 9️⃣ Start Your Own Firmware: Develop and **Have Fun!**

---

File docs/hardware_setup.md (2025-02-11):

# Hardware Setup for Axel

This guide provides instructions on setting up Axel for running examples, basic firmware, and tests. Following this setup ensures proper functionality and helps users integrate Axel into their own projects.

---

## Mounting Axel

Axel can be used in two configurations:

1. **Attached to the Back of the Motor** – Ideal for compact setups where Axel is mounted directly on the motor.
2. **Placed Remotely from the Motor** – Allows flexibility in placement, though an external encoder may be required if necessary for the desired control mode.

---

## General Setup

1. **Solder the Motor Phase Wires**

   - Axel has **three motor output phases** labeled **A, B, and C**.
   - Solder these to the appropriate motor wires—typically, BLDC motors have three wires corresponding to these phases.
   - If the motor spins in the wrong direction later, simply swap **any two** of the three phase connections.

2. **Check Power Connections**

   - Ensure your power supply matches **Axel’s voltage range (10-54V)**.
   - Double-check polarity before connecting.

---

## Encoder Setup

In our `examples/`, `firmware/`, and `tests/`, we utilize the onboard **AS5047P** magnetic encoder. Users must ensure the following setup:

- A **motor** with a **diametrically polarized magnet** mounted on its output shaft.
- The **magnet should be positioned at a distance of approximately 2mm from the encoder**.
- Proper alignment of the magnet and encoder is crucial – they should be directly on top of each other.
- A misalignment margin of about **1-2mm is acceptable but should be minimized** for optimal performance.

---

By following these guidelines, users can ensure accurate motor control and a stable setup for testing and development with Axel.

> **Note:** `/firmware` and `/examples` are still in development. Check out the [Project Status](#📊-project-status) section for the latest updates.

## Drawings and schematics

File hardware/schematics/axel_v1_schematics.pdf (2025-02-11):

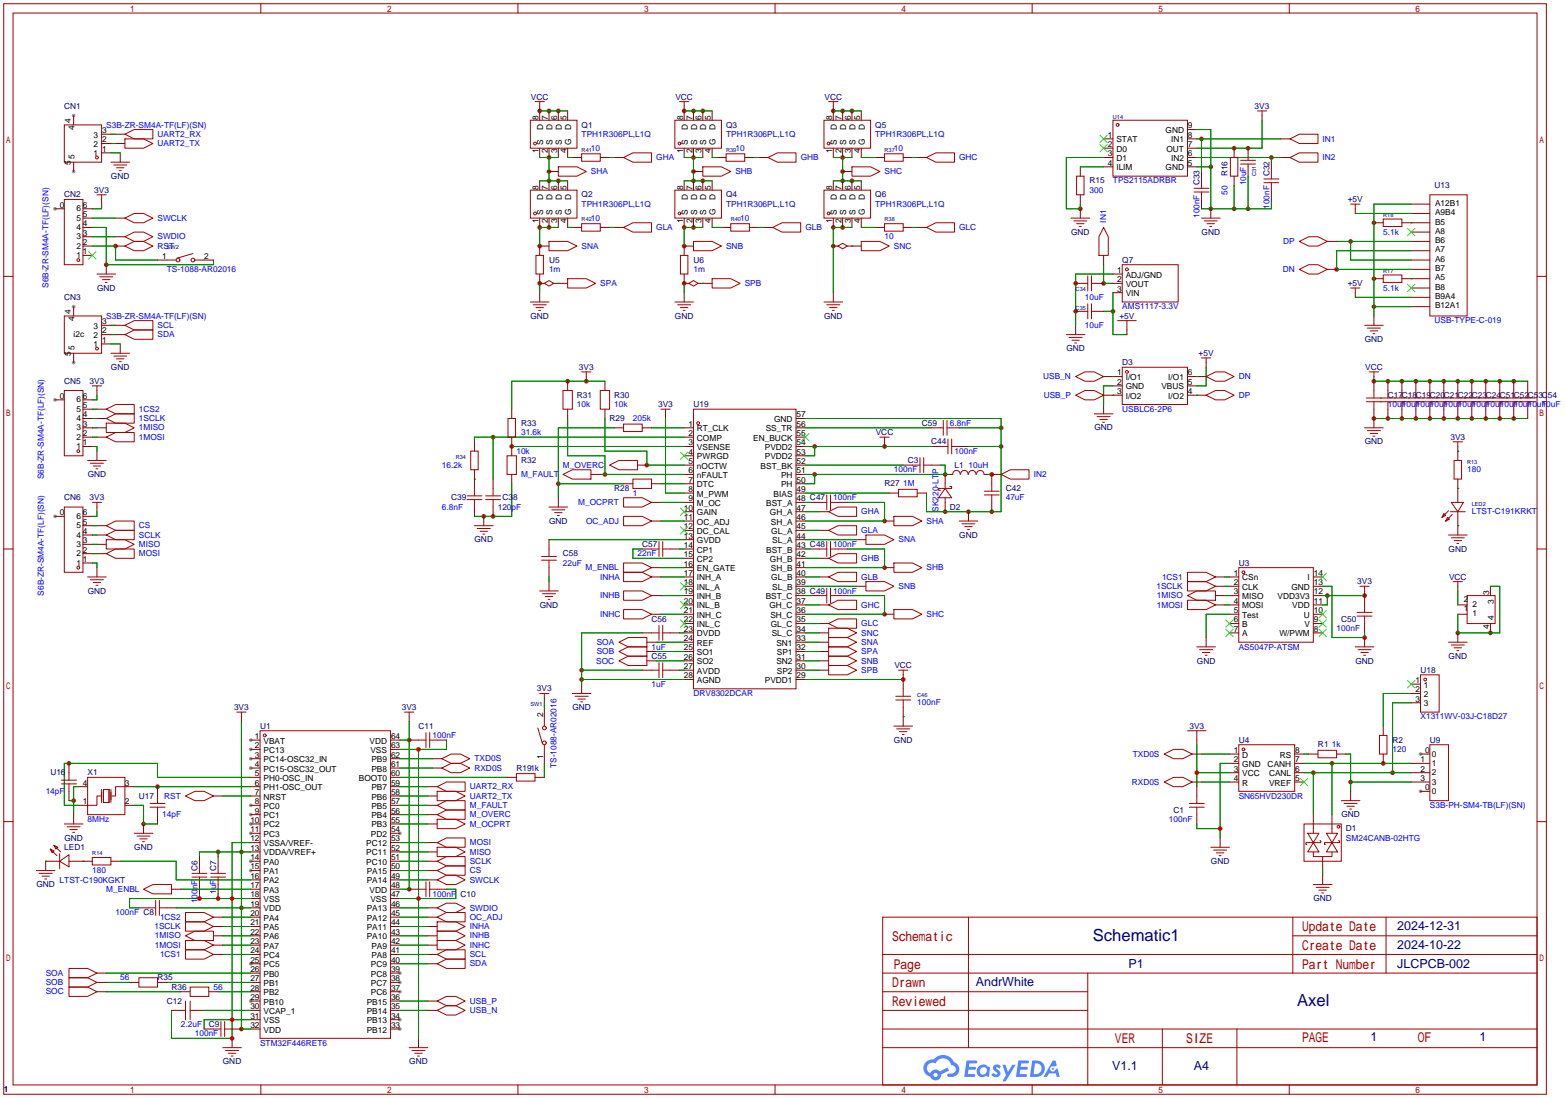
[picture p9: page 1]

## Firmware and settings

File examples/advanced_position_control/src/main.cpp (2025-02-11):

#include <Arduino.h>
#include <SPI.h>
#include <SimpleFOC.h>
#include <SimpleFOCDrivers.h>
#include <encoders/as5047/MagneticSensorAS5047.h>

#include "pinout.h"

#define MOTOR_POLE_PAIRS 11 // number of pole pairs on your motor

#define PID_VELOCITY_P 0.2f  // proportional constant of PID
#define PID_VELOCITY_I 20.0f // integral constant of PID
#define PID_VELOCITY_D 0     // derivative constant of PID
#define SUPPLY_VOLTAGE 24.0f // maximal voltage to be set to the motor
#define VELOCITY_LIMIT 50.0f // maximal velocity of the position control
#define LPF_VELOCITY_Tf                                                        \
  0.01f // velocity low pass filtering time constant. the lower the less
        // filtered
#define ANGLE_P 20.0f // angle P controller

#define INITIAL_TARGET 0.0f     // initial desired position in radians
#define SERIAL_BAUD_RATE 115200 // serial baud rate

#define SHUNT_RESISTOR 56
#define AMPLIFICATION_GAIN 10
#define PHASE_A_ADC_PIN SOA
#define PHASE_B_ADC_PIN SOB

BLDCMotor motor(MOTOR_POLE_PAIRS);
BLDCDriver3PWM driver(INHA, INHB, INHC, M_ENBL);
MagneticSensorAS5047 sensor(SPI1_CS);
InlineCurrentSense current_sense(SHUNT_RESISTOR, AMPLIFICATION_GAIN,
                                 PHASE_A_ADC_PIN, PHASE_B_ADC_PIN);

float target_angle = INITIAL_TARGET;
Commander command = Commander(Serial);
void doTarget(char *cmd) { command.scalar(&target_angle, cmd); }

void setup() {
  Serial.begin(SERIAL_BAUD_RATE);  // use monitoring with serial
  SimpleFOCDebug::enable(&Serial); // enable more verbose output for debugging
  motor.useMonitoring(Serial);

  sensor.init();             // initialise magnetic sensor hardware
  motor.linkSensor(&sensor); // link the motor to the sensor

  // Hardware-specific initialization for the DRV8302
  pinMode(M_OCPRT, OUTPUT);
  digitalWrite(M_OCPRT, LOW); // enable over-current protection
  pinMode(M_OC_ADJ, OUTPUT);
  digitalWrite(M_OC_ADJ, HIGH); // set the maximum over-current limit possible
  driver.voltage_power_supply = SUPPLY_VOLTAGE;
  driver.init();
  motor.linkDriver(&driver); // link the motor and the driver

  current_sense.linkDriver(&driver); // link the driver to the current sense

  motor.foc_modulation =
      FOCModulationType::SpaceVectorPWM; // choose FOC modulation
  motor.controller =
      MotionControlType::angle; // set motion control loop to be used

  motor.PID_velocity.P = PID_VELOCITY_P;
  motor.PID_velocity.I = PID_VELOCITY_I;
  motor.PID_velocity.D = PID_VELOCITY_D;

  motor.voltage_limit = SUPPLY_VOLTAGE;
  motor.velocity_limit = VELOCITY_LIMIT;
  motor.LPF_velocity.Tf = LPF_VELOCITY_Tf;
  motor.P_angle.P = ANGLE_P;

  motor.init();                           // initialize motor
  current_sense.init();                   // init current sense
  motor.linkCurrentSense(&current_sense); // link the current sense to the motor
  current_sense.skip_align = true;        // true or false = up to you
  motor.initFOC();                        // align sensor and start FOC

  command.add('T', doTarget, "target angle"); // add target command T

  Serial.println(F("Motor ready."));
  Serial.println(F("Set the target angle using serial terminal:"));
  _delay(1000);
}

void loop() {
  motor.loopFOC();
  motor.move(target_angle);
  command.run();
}

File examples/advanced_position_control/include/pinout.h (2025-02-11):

#ifndef PINOUT_H
#define PINOUT_H

/*
 * pinout.h
 *
 * This header file defines the hardware pinout configuration for the STM32
 * microcontroller used in Axel. The pin assignments reflect the specific
 * connections outlined in the schematic and are designed for peripherals, motor
 * control, and debugging.
 *
 * Notes:
 * - Peripheral instances (e.g., SPI1, UART1) correspond to STM32 documentation.
 * - Pin definitions follow STM32 naming conventions (e.g., PA5 = Port A, Pin
 * 5).
 */

/**************************** Oscillator ****************************/
#define OSC_IN_PIN PH0  // Main oscillator input (8 MHz)
#define OSC_OUT_PIN PH1 // Main oscillator output (8 MHz)

/******************************* GPIO *******************************/
#define LED PA2 // Onboard status LED (LED 1)

/********************* Communication Interfaces *********************/

// UART1 (USART1)
#define UART1_TX PB6 // UART1 Transmit
#define UART1_RX PB7 // UART1 Receive

// SPI1 (Primary SPI)
#define SPI1_CS PC4   // Chip Select for onboard encoder
#define SPI1_CS2 PA4  // Chip Select for external encoder
#define SPI1_SCLK PA5 // SPI1 Clock
#define SPI1_MISO PA6 // SPI1 MISO
#define SPI1_MOSI PA7 // SPI1 MOSI

// SPI3 (Secondary SPI)
#define SPI3_CS PA15   // Chip Select
#define SPI3_SCLK PC10 // SPI3 Clock
#define SPI3_MISO PC11 // SPI3 MISO
#define SPI3_MOSI PC12 // SPI3 MOSI

// I2C3
#define I2C3_SCL PA8 // I2C3 Clock
#define I2C3_SDA PC9 // I2C3 Data

// CAN1
#define CAN1_TX PB9 // CAN1 Transmit
#define CAN1_RX PB8 // CAN1 Receive

// USB OTG HS
#define USB_DP PB15 // USB Data+
#define USB_DM PB14 // USB Data-

/*************************** Motor Control **************************/

// Driver Control
#define M_ENBL PA3    // Motor driver enable
#define M_OC_ADJ PA12 // Overcurrent adjustment
#define M_OCPRT PB3   // Overcurrent protection switch

// PWM Inputs (High Side)
#define INHA PA11 // PWM for high-side bridge A
#define INHB PA10 // PWM for high-side bridge B
#define INHC PA9  // PWM for high-side bridge C

// Current Sensors (ADC1)
#define SOA PB0 // Current sense phase A
#define SOB PB1 // Current sense phase B

// Diagnostic Signals
#define M_FAULT PB5 // Motor driver fault signal
#define M_OVERC PB4 // Overcurrent signal

/***************************** Debugging ****************************/
#define SWDIO PA13 // SWD I/O
#define SWCLK PA14 // SWD Clock

#endif // PINOUT_H
